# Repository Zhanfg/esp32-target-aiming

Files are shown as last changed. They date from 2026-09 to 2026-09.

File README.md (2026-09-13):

# esp32-target-aiming

ESP32-S3 上的本地视觉目标锁定系统。摄像头找到目标，单片机算角度和轨迹，驱动双轴电机舵盘
把目标压回画面中心。

上位机只在开发期用，负责算法验证和标定。运行时不参与。

## 硬件

| 部件 | 选型 |
|---|---|
| 主控 | ESP32-S3 N16R8（16MB Flash / 8MB PSRAM） |
| 摄像头 | OV2640（主）/ OV5640（备） |
| 电机 ×2 | JGB37-520 12V 有刷减速电机，带霍尔编码器 |
| 驱动 | TB6612FNG 双路 H 桥，一片驱两轴 |
| 反馈 | ESP32 PCNT 硬件正交解码，四倍频 |
| 发射器 | 抽象接口 + 占位实现，型号待定 |
| 工具链 | VSCode + PlatformIO，C++17 |

## 目录

```
esp32-target-aiming/
├─ 00_MASTER_SPEC/      规格书与统一架构方案
├─ 01_PRIOR_ART/        现有来源与专利梳理
├─ 02_REQUIREMENTS/     方案设计、标定推导、硬件接线
├─ 03_CAD/              MST-01A ~ E 结构模型
├─ 04_SIMULATION/       准静态、瞬态、参数扫描
├─ 05_FIRMWARE/         ESP32-S3 固件、算法参考实现、I/O 映射
├─ 06_BOM/              物料清单
├─ 07_EXPERIMENTS/      工具链与 A ~ E 实验
├─ 08_DATA/             实验原始数据
├─ 09_PLOTS/            结果图表
├─ 10_FAILURE_ANALYSIS/ 失效分析
└─ 11_PUBLICATION_NOTES/ 论文与专利记录
```

依赖方向单向向下：`main → control → hal`，`vision` / `calibration` / `comms` 只依赖
`aim_types`，`math` 是公共底座。细节见 [02_REQUIREMENTS/方案设计.md](02_REQUIREMENTS/方案设计.md)。

## 几个设计取舍

先在 PC 上用 Python 把算法跑通再移植到单片机。参数在板子上盲调，出了问题分不清是算法错
还是传感器噪声大。

角度比较一律走 `angle_utils` 的环绕分支。现在按 ±180° 限位，将来换滑环做 360° 连续旋转时
控制算法不用重写。

提前量按执行机构滞后算。激光直瞄没有弹丸飞行时间，前视时间只由三部分组成：驱动延迟、
机械稳定时间、剩余角度除以最大角速度。

发射器需要显式 armed 且处于锁定态才允许触发，急停无条件生效。

## 当前状态

| 阶段 | 内容 | 状态 |
|---|---|---|
| P0 | 仓库骨架、PlatformIO 工程 | 进行中 |
| P1 | 标定层（内参 / 畸变 / 像素↔角度） | 待开始 |
| P2 | 算法核心与 PC 验证 | 进行中 |
| P3 | 视觉流水线 | 待开始 |
| P4 | 电机闭环控制 | 待开始 |
| P5 | 整机标定与精度评估 | 待开始 |
| P6 | 交付文档 | 待开始 |

阶段划分与验收指标见 [02_REQUIREMENTS/方案设计.md](02_REQUIREMENTS/方案设计.md) 第 11 节。

## 安全

这套东西含电机驱动机构和发射器接口。

上电前对照实物原理图核对 `05_FIRMWARE/include/config.h` 里的全部引脚。电机和逻辑分开供电、
单点共地，电机侧并一个 470µF 以上的电解电容。

电机铭牌上的减速比和编码器 PPR 要如实填进配置。这两个数字填错，整条角度链会按比例偏，
而且症状不直观。

发射器相关代码在完成安全评审前不要接真实装置。

## 文档

- [方案设计](02_REQUIREMENTS/方案设计.md)：架构、坐标系约定、算法公式、双环 PID、实施计划与验收标准
- [标定与几何推导](02_REQUIREMENTS/标定与几何推导.md)：针孔模型、畸变与反畸变迭代、像素↔角度互逆性证明、仿射最小二乘、精度预算
- [硬件接线与选型](02_REQUIREMENTS/硬件接线与选型.md)：BOM、引脚分配表、供电与接地、TB6612 真值表、上电检查清单

## 许可

MIT，见 [LICENSE](LICENSE)。

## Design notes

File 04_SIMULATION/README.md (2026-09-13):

# MST-01 数值仿真模型

这是规格书 §23 要求的纯软件力学模型，用 Python 与 numpy 求解，不依赖有限元软件，
也不需要 scipy。模型覆盖 §13 的 A/B/C 三个原型：A 普通膜片，B 单级 snap，
C 双级串联 snap。

模型只服务于静态与动态规律，不证明任何方案更优。§5.3 要求保留单级对照，
并允许得出「双级应被淘汰」的结论，下面的初步结论按模型实际给出的结果写。

## 目录

```text
04_SIMULATION/
├─ README.md
├─ requirements.txt
├─ conftest.py                 # pytest 的路径引导
├─ models/
│  ├─ membrane.py              膜片非线性力—位移
│  ├─ vmt.py                   von Mises truss 双稳单元
│  ├─ chain.py                 一维串联链与元件
│  ├─ solver.py                准静态求解与速度 Verlet 瞬态积分
│  └─ params.py                名义参数、出处与 A/B/C 装配
├─ studies/
│  ├─ common.py                运行、事件检测与输出工具
│  ├─ quasi_static.py          §23.1
│  ├─ transient.py             §23.2
│  └─ parameter_study.py       §23.3
├─ tests/                      模型性质单元测试
└─ results/                    运行后产出的 CSV 与图
```

## 用法

```bash
pip install -r requirements.txt
python studies/quasi_static.py
python studies/transient.py
python studies/parameter_study.py
python -m pytest -q
```

matplotlib 是可选的，缺库时 study 照常出数字与 CSV，只是不产图。

## 模型

### 膜片

把膜片当成预张紧圆膜，夹持边界固定，中心被推杆顶出。采用 Föppl 大挠度薄膜
理论的单模态近似，挠曲形状取抛物线 w(r)=w0(1-(r/a)^2)，解轴对称面内场后积分
应变能再对中心挠度求导，得到

    F(w) = 2·π·N0·w + π·E·t·(7-ν)/(6·(1-ν)·a²) · w³

线性项来自预张力 N0=E·t·ε0/(1-ν)，三次项来自几何大挠度引起的膜内拉伸。
推导步骤写在 `models/membrane.py` 的文件头。抛物线是单模态近似，系数为量级正确，
不是椭圆积分精确解。

假设与局限：轴对称、忽略弯曲刚度、线弹性小应变、预张力与几何拉伸解耦、推杆
半径远小于膜半径。硅胶的粘弹滞后没有建模，会高估回弹能量。挠度接近半径时
误差增大。参数见 `models/params.py`。

### von Mises truss

两根斜杆加可滑动底端。势能写成

    U(h,u) = k_bar·(ℓ-L)² + k_base·u²,  ℓ=sqrt((a+u)²+h²)

给定顶点高度 h，先由 ∂U/∂u=0 解出底端张开量，再用包络定理得到顶点力。
`k_base` 就是规格书 §5.4 与 SRC-04 讨论的边界刚度：它越大越接近锁定支撑，
snap 力随边界刚度单调上升；边界太软时双稳性变弱。这一点在准静态边界敏感性
里可以直接看到。

假设与局限：杆线弹性、忽略杆弯曲与屈曲、忽略摩擦与间隙、底端弹簧线性、
对称二维运动、质量集中在顶点。`k_bar` 是把弹性片弯曲柔度折算到杆轴向的等效
参数，不是材料拉伸刚度，必须实测标定。

### 串联链与求解

A/B/C 都装配成一维串联链。瞬态用力控：外力在 20 ms 内按 smoothstep 升到目标值
后保持。用力控而不是刚性位移驱动，是为了让作动器有明确的力上限，snap 之后
不会持续注入能量。积分用速度 Verlet（kick-drift-kick）固定步长；无阻尼时它是
辛格式，能量误差随步长二阶收敛。力表用三次 Hermite 插值，避免分段线性折点在
高速运动时影响能量。

准静态用位移控牛顿法沿稳定分支前进，输入力的第一个局部极大就是 snap 阈值。
这样不依赖「牛顿失败」这种脆弱判据。到达极限点后停止跟踪。

步长选择：按最高关注频率取周期的 1/100 以下，默认 dt=1e-6 到 5e-7 s；
能量守恒测试用无阻尼自由振动核对，相对漂移在 1e-6 量级。

已知忽略项：摩擦、重力、气压反作用与流体耦合、接触碰撞的细节、膜片面内质量
分布、疲劳与塑性、面外失稳与不对称分岔、作动器自身动力学与柔度、材料粘弹。
这些是最可能让定量结论失真的地方。

## 与规格书 §23 的对应

| 规格书 | 文件 | 产出 |
|---|---|---|
| §23.1 准静态 | `studies/quasi_static.py` | 力—位移、稳定分支、snap 点、级序、边界敏感性 |
| §23.2 瞬态 | `studies/transient.py` | snap 后速度、级间间隔、膜片运动、结构振铃 |
| §23.3 参数扫描 | `studies/parameter_study.py` | 边界刚度、预载、级间失配、膜片刚度、阻尼 |

## 名义参数与出处

| 参数 | 值 | 来源或依据 |
|---|---|---|
| 硅胶膜 E | 1 MPa | 硬度计 30A 量级估计，待实测标定 |
| 硅胶膜 t / a | 0.2 mm / 8 mm | §1.2 横向 15–25 mm 量级 |
| 硅胶预应变 | 5% | 手工张紧安装的典型量级，待实测标定 |
| PET 膜 E / t | 3 GPa / 50 µm | PET 常见范围 2–4 GPa 量级估计，待实测标定 |
| VMT 半跨 / 杆长 | 8 mm / 10 mm | §1.2 核心模块 30–50 mm 长度量级 |
| VMT k_bar | 2000 N/m | 等效参数，名义 k_base 下 snap 力约 1.7 N，与膜片回复力可比，待实测标定 |
| VMT k_base | 1e4 N/m | 接近锁定支撑，保证单级能 snap；扫描变量 |
| engagement gap | 0.6 mm | 量级估计，扫描变量 |
| 顶点质量 | 0.5 g | 零件级量级估计，依赖 CAD，待实测标定 |
| 阻尼 | 0.01 N·s/m | 约单元临界阻尼 1%，等效线粘性，待实测标定 |

## 基于模型的初步结论

这些是模型输出，不是实测结论，必须用 §16 的 A1/B1/C1 实验确认。

### STOP-01 单级 snap 相对普通膜片

同一力曲线下，A 版膜片峰值速度约 0.47 m/s，B 版约 8.9 m/s，模型里单级 snap 的
膜片速度约高 19 倍。触发力约 1.7 N，与失稳单元的 snap 力一致。按这个结果，
STOP-01 没有被触发，单级 snap 值得继续做实验。注意 A 版的 0.47 m/s 是慢推下
膜片自身的响应速度，B 版的速度来自 snap 释放，两者口径一致但含义不同。

### STOP-02 双级是否更差

名义参数（两级相同、gap 0.6 mm）下，C 版膜片峰值速度约 10.6 m/s，只比 B 版高约
18%，输入功却从 20 mJ 升到 38 mJ。事件顺序不稳定：两级相同时第二级先触发，
第一级后触发，间隔 7.21 ms；当第二级刚度比第一级高 1.5 倍以上时顺序翻转成
第一级先触发。整段失配扫描的间隔落在 2.32–4.20 ms，最大 4.20 ms 出现在刚度比
1.0 处。准静态下两级几乎同时到达
fold，静态分不出先后。

按 §30 的口径，双级更复杂、顺序不固定、输出提升有限，本模型倾向于支持 STOP-02，
即回退单级。这个判断只在名义参数与当前模型假设下成立。

### 膜片柔度

膜片刚度扫描显示，峰值输出速度对柔度不是单调：太硬的膜（刚度放大 100 倍）
把速度压到约 3.3 m/s，偏软一侧在刚度放大 0.1 倍处有一个内部低点（7.00 m/s），
之后回升，在刚度放大 0.3 倍到 3 倍之间有一片较宽的最佳区（8.74–9.05 m/s）。
模型没有气动侧，无法直接判断「太软的膜吸收 snap 输出」，只能给出机械侧速度
随柔度的变化。要判断空气脉冲效率，需要在模型里加入气腔与压力，或直接用实验
的 pressure-time 数据。

## 模型依据

- 膜片：Föppl / Hencky 大挠度薄膜理论，单模态（Galerkin）近似，推导见
  `models/membrane.py`。
- 双稳单元：经典 von Mises truss 的双稳势能，配合可滑动底端的边界弹簧；
  串联 snap 与边界刚度可调的概念来源是 SRC-04（Santos 2026），本模型只借用
  概念，不复现其结构或数据。
- 瞬态：速度 Verlet 辛积分，误差二阶收敛；步长收敛由 `solver.convergence_check`
  和测试核对。
- 没有使用 scipy，依赖只有 numpy。

## 没有来源的参数如何处理

`models/params.py` 里每个量都标注了出处或估计依据。材料模量、等效杆刚度、
质量、阻尼、gap 这些没有实测支撑的，写「量级估计，依据：…」或「待实测标定」。
绝对数值不要直接当设计输入，先做 §17 的标定实验。

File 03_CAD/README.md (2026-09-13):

# 03_CAD

结构模型按规格书 §13 的五级原型分开，一级一个子目录：

- `MST-01A/`：普通膜片基线，无 snap-through，低速执行器直接推膜片。
- `MST-01B/`：单级 snap，一个失稳单元。
- `MST-01C/`：双级串联 snap，两个失稳单元，要能判定两级先后。
- `MST-01D/`：可切换边界研究版，locked / released support 或等效的边界改变，带多种预载状态。
- `MST-01E/`：自动供给完整版，6–8 位供给盘、索引机构、Mode B 相关结构。

§14 定了 A → B → C → D → E 的次序，不许跳级，所以目录编号也按这个顺序推进，后续级别在上一级
达标前不动。

设计原则见 §22：模块化（§22.1 要求至少拆成可独立更换的几块）、可拆可测（§22.2，传感靶这类装在运动件
上的附件要能单独拆下做对照）、关键件一体化（§22.3）。§5 的 Stage 1 / Stage 2 两级机械定义和 §6 的
膜片安装方式都会落到具体零件上，失稳单元的候选结构见 §7。

文件名带版本，改了结构就另存一版，别覆盖上一版，方便回查某次实验用的是哪套模型。

## 各级原型的关系

A 到 E 五级沿同一条轴向串联，D 与 E 的核心支持单级与双级两种：

| 级别 | 中间级 | 失稳单元 | 释放卡榫 | 轴向长度 |
|---|---|---|---|---|
| A | 低速执行器直推 | 无 | 无 | 32 mm |
| B | 单个 von Mises truss | 1 个 | 有 | 38 mm |
| C | 两个 von Mises truss 串联 | 2 个 | 有 | 44 mm |
| D | 边界切换加预载 | 1 或 2 个 | 有 | 36 / 47.5 mm |
| E | D 级加 6–8 位供给盘 | 1 或 2 个 | 有 | 46.25 / 58.25 mm。装 6/8 位盘后横向 58.00 / 69.04 mm，超出 §1.2 的 15–25 mm 目标，轴向双级也超出 8.25 mm（`MST-01E` 几何自检，非实测），见 `../00_MASTER_SPEC/DESIGN_DECISION_LOG.md` D-15、`../02_REQUIREMENTS/RISK_REGISTER.md` RSK-16 |

A 没有储能元件，按 §13 是直接推动的基线，不需要释放卡榫。B 与 C 用同一套自锁卡榫加电磁铁拔销的
释放机构。三级共用 FRAME、DIAPHRAGM_MODULE，C 额外多一个 STAGE_2。D 级加 BOUNDARY_MODULE 与
PRELOAD_MODULE，E 级再加 MAGAZINE_MODULE。

## 参数库怎么用

`lib/` 是纯 Python，算尺寸、体积、包围盒、质量都不需要 FreeCAD：

- `lib/params.py`：所有结构尺寸、材料密度、布局锚点、参数来源登记表 `PARAM_SOURCES`。
- `lib/frame.py`：FRAME 模块几何。
- `lib/stage.py`：STAGE_1 / STAGE_2 的 von Mises truss 单元，弹性片是独立件。
- `lib/membrane.py`：DIAPHRAGM_MODULE，膜片加前后两片可拆压环。
- `lib/release.py`：RELEASE_MODULE，自锁卡榫与电磁铁拔销，含自锁余量计算。
- `lib/boundary.py`：BOUNDARY_MODULE，D 级的 locked / released 可切换边界。
- `lib/preload.py`：PRELOAD_MODULE，D 级的可换垫片预载状态。
- `lib/magazine.py`：MAGAZINE_MODULE，E 级的 6/8 位供给盘与索引。
- `lib/checks.py`：件数、包围盒、体积、质量、envelope 对照。
- `lib/freecad_export.py`：把 Solid 列表转 FreeCAD 实体并导出 STEP / FCStd，best-effort。

改尺寸先改 `params.py`，各级 `build.py` 会跟着变。`params.layout(level)` 给出该级沿 Z 的模块区间。

## 重建命令

在 `03_CAD/` 目录下：

```powershell
python MST-01A/build.py
python MST-01B/build.py
python MST-01C/build.py
python MST-01D/build.py                  # 默认单级 locked P0
python MST-01D/build.py --core dual --boundary released --preload P2
python MST-01E/build.py                  # 默认单级 6 位
python MST-01E/build.py --core dual --positions 8
```

每跑一次打印一份几何自检：件数、包围盒、体积、按材料质量估算、模块件数与 envelope 判定。
追加 `--freecad` 会尝试导出 STEP 与 FCStd，当前环境没装 FreeCAD 时会打印跳过提示，不影响自检。

## 与 §22 三条原则的对应

- §22.1 模块化：C 级可拆成 FRAME、STAGE_1、STAGE_2、DIAPHRAGM_MODULE、RELEASE_MODULE 五块，
  外加 OUTPUT 传力杆；B 级去掉 STAGE_2；A 级把中间级换成 ACTUATOR。
- §22.2 可测试性：压环用 M2 螺钉夹紧，松开即可换膜片；失稳单元弹性片由夹块与铰销定位，
  松开夹块螺钉可整片抽出更换；框架顶部敞开，从上方能拍到 snap 过程；自锁卡榫与电磁铁露在外侧。
- §22.3 不要过早一体化：打印件只做框架、夹块、滑块、压环、卡榫座与电磁铁座，弹性件与销都是
  独立标准件或片材，第一版优先看得见、拆得开、测得到。

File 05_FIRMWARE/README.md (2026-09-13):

# MST-01 微型定向脉冲平台固件（第二期）

摄像头与脉冲核心同轴装在旋转云台上。pan 为水平旋转，tilt 为俯仰。两轴各由一台位置
舵机驱动，ESP32-S3 直出 50Hz PWM，或有总线反馈的舵机时读回位置与负载。整机由三块组成：
找目标的视觉、指向目标的云台、产生脉冲的两级串联失稳机械核心。

第二期执行层：舵机指向、两级脉冲核心、旋转供给盘。第一期的电机闭环、TB6612、编码器层
已整体删除。状态机做成双区域：区域 A 管发射周期，区域 B 管指向质量，跨区域用守卫矩阵
约束。故障锁存后唯一清除路径是 `SAFE → HOME`。

架构与安全设计见 `00_MASTER_SPEC/统一架构方案.md` 第 6 节，引脚见 `05_FIRMWARE/io-map.md`，
故障码见 `05_FIRMWARE/fault-codes.md`。

## 1. 构建 / 烧录 / 监视

```bash
cd 05_FIRMWARE

# 编译（开发环境，带逐帧遥测）
pio run

# 编译并烧录
pio run -t upload

# 打开串口监视器（115200）
pio device monitor

# 发布环境（-O2、关闭逐帧遥测）
pio run -e esp32-s3-devkitc-1-release
```

> 环境：VSCode + PlatformIO（Arduino 框架）+ C++17。外部库只依赖 `espressif/esp32-camera`，
> LEDC、I2C、Preferences 都来自 Arduino-ESP32 内置的 ESP-IDF 组件。

## 2. 上电前核对

`include/config.h` 里带 `// 待实测标定` 的引脚和参数都是占位默认值。首次烧录前重点确认：

- 摄像头 DVP 数据线 `CAM_PIN_Y2..Y9` 的顺序。接错会黑屏或花屏，一般不会损坏硬件。
- 舵机 PWM 脚（PAN_CMD=14、TILT_CMD=21）与摄像头、USB、Flash/PSRAM 占用脚不冲突。
- I2C0（GPIO45/46）是 strapping 脚，外接上拉会影响复位电平，必须核对。
- MCP23017 输入的外部上拉/下拉已按信号极性就位：许可类（FIRE_INHIBIT、EXTERNAL_ALLOW）
  外部下拉、开路即禁止；`MECH_RECOVERED` 常闭干接点对地、外部上拉。
- 参考开关 `PAN_HOME`、`TILT_HOME` 的触发方向与 `HOME_*_DIR` 一致，否则归零会超时进 FAULT。
- 释放链硬件与门树、单稳态与负载开关已搭好，且逐条断开输入时释放无动作（架构文档 §6.11）。

## 3. 模块职责

| 文件 | 职责 |
|---|---|
| `platformio.ini` | 构建配置：芯片、PSRAM、Flash 分区、依赖、编译开关、发布环境 |
| `include/config.h` | 全部引脚、机械参数、安全阈值、通信参数 |
| `src/aim_types.h` | 双区域状态、故障码、跨模块数据结构 |
| `src/math/angle_utils.*` | 角度归一化、角差、限速趋近 |
| `src/hal/servo.*` | 舵机抽象：PWM 实现 + 总线占位实现，编译期选择 |
| `src/hal/io_expander.*` | MCP23017 的 I2C0 驱动，读失败落安全侧 |
| `src/hal/safety_gate.*` | 软件互锁判定与武装锁存，硬件与门之外的第二层 |
| `src/hal/transmitter.*` | 第一期发射器抽象，第二期由四路命令层取代，保留占位 |
| `src/control/servo_axis.*` | 单轴指向控制：限幅、变化率限制、有反馈时位置校正 |
| `src/control/home.*` | 上电归零五步流程，参考开关 + 3 秒超时 |
| `src/calibration/*` | 内参、畸变、仿射标定的存取与最小二乘解算 |
| `src/vision/*` | 取帧、降采样、HSV、连通域、亚像素质心 |
| `src/comms/telemetry.*` | 串口 CSV 遥测与事件行 |
| `src/main.cpp` | 初始化、双区域状态机、安全策略、看门狗 |

## 4. 遥测格式

固件走两条遥测线，前缀不同，用途不同。

`MST,` 是规格书 §19 的实验记录，每发一条，17 个字段：

```
MST,timestamp,experiment_id,prototype_version,mechanism_version,mode,boundary_state,
    preload_state,membrane_id,payload_id,cycle_count,stage1_event,stage2_event,
    mechanism_recovered,magazine_position,magazine_index_ok,fault_code,operator_note
EVT,<t_ms>,<tag>,<message>
```

`DIAG,` 是每控制拍的帧轨迹，由 `AIM_VERBOSE_TELEMETRY` 控制，开发期打开、发布期关闭，
16 个字段：

```
DIAG,timestamp_ms,loop_us,obs_valid,obs_dropped,px,py,confidence,
     pan_deg,tilt_deg,pan_target_deg,tilt_target_deg,
     err_pan_deg,err_tilt_deg,err_deg,aim_state,has_feedback
```

`err_deg` 是目标质心相对光轴的角偏差合成量，静态指向 RMSE 按它算；`loop_us` 是控制周期；
`aim_state` 的 3 与 4 对应 TRACKING 与 LOCKED，据此算锁定建立时间。字段口径见
`src/comms/telemetry.h`。

发布环境（`AIM_VERBOSE_TELEMETRY=0`）只留 `MST,` 低频心跳行，`DIAG,` 行不输出。故障码见
`fault-codes.md`。

## 5. 安全要点

- 释放链的物理门控由外部与门与负载开关保证，软件互锁只是第一道闸（架构文档 §6.6）。
- `FAULT` 锁存，`FAULT → READY` 不存在；软故障用 `CLEAR` 后走 `SAFE → HOME`，硬故障需断电。
- 归零期间释放链强制断开，参考开关未全中不进入 `READY`。
- 无反馈 PWM 舵机不能检测失速，失速检测依赖总线舵机反馈或电流监控，需台架验证。

## 6. 批次编号命令

膜片与载荷的批次号供实验追溯，来源只能是操作者输入。串口命令写入后存 NVS（命名空间
`aim_batch`，键 `membrane`、`payload`），断电不丢，上电由 `setup()` 读回，组装遥测时填入
`membrane_id`、`payload_id`。两字段都是 uint16，取值 0 .. 65535，0 表示未设置。

```
SET MEMBRANE <id>    # 设膜片批次编号
SET PAYLOAD <id>     # 设载荷批次编号
STATUS               # 输出 ST,membrane_id,<n> 与 ST,payload_id,<n>
```

参数非数字或超出 0 .. 65535 会报错并保持原值；NVS 写入失败也会回退原值。这两条命令在
`calib_shell` 的 `HELP` 里也能查到。

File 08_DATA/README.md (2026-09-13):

# 08_DATA

实验原始数据落在这里。§20 这个目录本身不分子目录，用文件名区分实验与日期。

字段定义、CSV 约定、枚举对照和各级数据文件与列定义表的对应，见 `DATA_SCHEMA.md`。
本文只给目录用途和归档流程。

每次动作保存一行，字段按规格书 §19：

```
timestamp
experiment_id
prototype_version
mechanism_version
mode
boundary_state
preload_state
membrane_id
payload_id
cycle_count
stage1_event
stage2_event
mechanism_recovered
magazine_position
magazine_index_ok
fault_code
operator_note
```

A 到 E 各级的采集记录都进这里，`experiment_id` 里带上原型级别，免得混在一起。遥测原始 CSV 可以先
留在 `07_EXPERIMENTS/` 对应级别下，按 `DATA_SCHEMA.md` 的列定义整理成规范字段后再归档到这里。
出图的数据从这份表读，不要在 `09_PLOTS/` 里手改数据。

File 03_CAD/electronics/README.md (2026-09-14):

# MST-01 释放门控电路板（release-gate）

本目录是释放路径的硬件门控板。它把统一架构方案 §6.6 的与门树、§6.5 的 H1/H2/H3/H4/H6
做成实体电路，让固件即使卡死或输出错误电平，也放不出一次释放。对应主规格 §10.3 的
`RELEASE_CMD` 输出与 §11 的四条互锁。

架构 §6.11 第一条说得很直接：这条不通过，后面所有状态机都是纸面。所以本板的设计重点不在
控制精度，而在每一个输入的失效方向，以及一块被卡住的 MCU 能造成什么。

信号极性和接口以 `02_REQUIREMENTS/interfaces.md` 第 5 节为准，引脚沿用
`05_FIRMWARE/include/config.h` 的 `RELEASE_CMD_PIN`、`STAGE1_STATE_PIN`、`STAGE2_STATE_PIN`
等定义。两者不一致时以接口文档为准，本板按接口文档的电平做。

## 1. 文件与用途

| 文件 | 用途 |
|---|---|
| `README.md` | 本文：设计说明、逻辑推导、极性表、H1 到 H6 落点、单点失效分析 |
| `release-gate.kicad_sch` | 原理图，KiCad 10 S-expression，含完整网表 |
| `release-gate.kicad_pcb` | 板图初版：外形、安装孔、布局、网表、地平面、执行链局部走线 |
| `release-gate.kicad_pro` / `.kicad_prl` | KiCad 打开时自动生成的工程文件 |
| `release-gate-schematic.pdf` / `.svg` | 原理图导出，供快速查看 |
| `release-gate-pcb.pdf` / `.svg` | 板图导出 |
| `bom.csv` | 物料清单，含位号、型号、数量、封装、作用 |
| `test-procedure.md` | 板级验证步骤，搭板后照做 |

本板不承担 H5（超出机械限位）。H5 由结构件上的物理止挡实现，见 `03_CAD` 各机型的结构件。

## 2. 供电与地

板上有两条供电，进板后各自串自恢复保险丝和防反：

- 逻辑轨 `+3V3`：从主控逻辑电源引入，经 `D14`（SS14 防反）与 `F1`（MF-MSMF050）。
  供五片 74HC、上拉/下拉和继电器（本版无继电器）。
- 执行轨 `V_ACT_IN`：从舵机与执行器电源引入，先过 `J7` 上的急停常闭触点变成 `V_ACT_SW`，
  再经 `F2`（MF-MSMF200）到释放电磁铁，另经 `F3`（MF-MSMF110）到预载执行器。
- 单点共地。逻辑地与执行地在板上汇到同一块铺铜，不另做隔离，避免地环路。

急停之后才出现 `V_ACT_SW`，这一点让急停独立于任何逻辑元件。后面所有 MOS 开关都只能
在 `V_ACT_SW` 存在时给执行器供电。

## 3. 与门树

### 3.1 逻辑表达式

```
Q1 = FIRE_INHIBIT_N · EXTERNAL_ALLOW · MECH_RECOVERED_N · POCKET_OR_MODE_A
Q2 = Q1 · ARMED_LATCH · RELEASE_PULSE · MASTER_ENABLE_GATED
MASTER_ENABLE_GATED = MASTER_ENABLE_RAW · FAULT_OK
FAULT_OK            = NOT(FAULT_LATCH)
POCKET_OR_MODE_A    = POCKET_ALIGNED OR MODE_A_RAW
```

Q2 经 `R22` 驱动低边 MOSFET `M1` 的栅极。M1 导通，释放电磁铁才通电；Q2 为低或悬空时 M1
关断。整条链上任何一级为假，释放都不可能发生。

### 3.2 器件选择

工程实践里做四输入与门，直接用一片 74HC21 最省。74HC21 是双 4 输入与门，一片正好给出
Q1 和 Q2 两级，不需要用 74HC08 拼树，也不用二极管与门凑，输入数、门数、传播延迟都对得上。
逻辑轨 3.3V，74HC 系列在 3.3V 下的输入阈值和驱动能力都够用。

其余逻辑按功能配：

- `U2` 74HC123：双可重触发单稳态，一半做释放脉宽钳位，一半做归零复位脉冲。
- `U3` 74HC74：双 D 触发器，一半做故障锁存，一半做武装锁存，异步置位/复位正好用来接
  故障置位和归零复位。
- `U4` 74HC11：三 3 输入与门，做三处 HOME 的与、武装时钟门、取消武装逻辑。
- `U5` 74HC14：六施密特反相器，做极性取反和慢边沿整形。
- `U6` 74HC08：四 2 输入与门，把故障锁存输出接进主使能和预载使能。

### 3.3 输入极性与开路行为

每个输入都按“开路即禁止”配偏置。外部上拉或下拉只是并上去，板端自己的偏置保证接插件
松脱、断线、掉电时落到禁止侧。执行器电源上的急停触点另算，它断的是功率。

| 信号 | 有效方向 | 板端偏置 | 开路结果 | 落点 |
|---|---|---|---|---|
| `FIRE_INHIBIT_N` | 高 = 未否决 | `R1` 10k 下拉，`R2` 串联 10k，`C1` 100n | 拉到低 | 否决，Q1 为假 |
| `EXTERNAL_ALLOW` | 高 = 许可 | `R3` 10k 下拉，`R4` 串联 10k，`C2` 100n | 拉到低 | 拒绝，Q1 为假 |
| `MECH_RECOVERED_RAW` | 低 = 机构已复位 | `R7` 10k 上拉，`C4` 100n | 拉到高 | 经 `U5A` 反相为低，Q1 为假 |
| `POCKET_ALIGNED` | 高 = 载荷对齐 | `R5` 10k 下拉，`R6` 串联 10k，`C3` 100n | 拉到低 | 对齐不满足，Q1 为假 |
| `MODE_A_RAW` | 高 = 模式 A 旁路 | 经 `JP1` 与外部常闭触点，`R27` 100k 下拉 | 拉到低 | 撤销旁路，退回要求真实对齐 |
| `ARM_CMD` | 高 = 请求武装 | `R8` 10k 下拉，`C5` 100n | 拉到低 | 不武装 |
| `DISARM_CMD` | 高 = 取消武装 | `R9` 10k 下拉，`C6` 100n | 拉到低 | 不取消，见 3.4 |
| `FAULT_CMD` | 高 = 软件请求故障 | `R10` 10k 下拉，`C7` 100n | 拉到低 | 不置故障，见 3.4 |
| `MCU_RELEASE_CMD` | 高 = 释放请求 | `R12` 10k 下拉，`R11` 串联 1k，`C8` 100n | 拉到低 | 无请求 |
| `MASTER_ENABLE_RAW` | 高 = 主使能有效 | `R18` 10k 下拉，`C13` 100n，且串急停触点 | 拉到低 | Q2 为假 |
| `PAN_HOME` / `TILT_HOME` / `MAG_HOME` | 高 = 已触发 | `R15` / `R16` / `R17` 10k 下拉，`C10` 到 `C12` 100n | 拉到低 | 视为未归零，故障锁存不能复位 |

`FIRE_INHIBIT_N` 与 `EXTERNAL_ALLOW` 的静态偏置在接口文档里规定为外部 10k 下拉，板端再各
并一只下拉，断线时两处都往低走。

### 3.4 两处不落到禁止侧但可接受的开路

`FAULT_CMD` 与 `DISARM_CMD` 开路时都拉到低。低电平分别表示“不置故障”和“不取消武装”。
两者都不是禁止侧电平，但它们本身只是软件发起的动作请求，缺失不会让释放更容易发生：
置故障是让系统更安全，取消武装也只是把武装锁存清零。真正的拦截已经由
`FIRE_INHIBIT_N`、`EXTERNAL_ALLOW`、`MASTER_ENABLE_RAW` 和故障锁存承担。这里如实标出，
免得把“开路即禁止”一概而论。

## 4. 单稳态钳时

### 4.1 电路

`MCU_RELEASE_CMD` 从 `J3` 进来，串 `R11`、对地 `C8`，接到 `U2A` 的 B 触发端（引脚 2）。
`U2A` 的 A 端（引脚 1）接 `GND`，使上升沿触发；`CLR`（引脚 3）接 `+3V3`。输出 Q（引脚 4）
是 `RELEASE_PULSE`，接到 Q2 的一个输入。RC 定时网络是 `R19` 与 `C15`，分别接在
`1REXT`（引脚 7）与 `1CEXT`（引脚 6）。

GPIO 直连的长驱动不再存在，释放命令必须先过这一级。MCU 把 `RELEASE_CMD` 拉高并保持，
单稳只输出一个固定宽度的脉冲，之后回到低，不会持续通电。

### 4.2 脉宽计算

74HC123 的脉宽按数据手册：

```
t_W ≈ K · R_EXT · C_EXT
```

其中 `K` 在 `C_EXT ≥ 1000 pF`、`VCC = 3.3V` 附近典型值约 1.0。取

- `R19 = 33 kΩ`，`C15 = 1 µF`，得 `t_W ≈ 33 ms`。

固件侧的软件脉宽是 `RELEASE_PULSE_MS = 30 ms`。硬件上限略大于软件脉冲，正常工作时由软件
结束释放，硬件不截断；MCU 卡在输出高时，硬件在约 33 ms 后强制关断。两侧都留了容差，实际
脉宽受电容容差（约 ±10%）、电阻容差和 `K` 的温度漂移影响，台架上用示波器测 `RELEASE_PULSE`
实测宽度，按结果微调 `C15`。执行器若需要更长动作时间，加大 `C15` 后重新验证。

`U2B` 用同样的公式做归零复位脉冲：`R20 = 22 kΩ`，`C16 = 1 µF`，得约 22 ms。

单稳是可重触发的。MCU 卡高只给一个上升沿，所以是一个脉冲；固件在释放脉冲有效期内不得
再次翻转 `RELEASE_CMD`，否则会把脉冲续长，这一条写进固件约束。

## 5. 负载开关

释放电磁铁的回流路径上串低边 N 沟道 MOSFET `M1`（AO3400A，SOT-23）：

- 栅极由 `Q2_OUT` 经 `R22`（100Ω）驱动，栅源之间有 `R21`（100k）下拉。Q2 悬空或走线断开时
  `R21` 把栅极拉到 `GND`，M1 关断。
- 漏极接 `EMAG_LO`（电磁铁回流端），源极接 `GND`。
- 电磁铁两端反并 `D1`（SS34），阴极朝 `EMAG_HI`，关断瞬间给感性电流一条续流回路。
- `V_ACT_SW` 到 `EMAG_HI` 之间串 `F2`（MF-MSMF200 自恢复保险丝），短路或堵转时限流。
- `V_ACT_SW` 对地挂 `D13`（SMBJ16A）做瞬态钳位。

预载执行器走同样结构：`M2` 栅极由 `PRELOAD_ENABLE` 驱动并带 `R23` 下拉，漏极 `PRELOAD_RET`
接 `J4` 的 2 脚。它的源极在板上不直接接地，改从 `J4` 的 3 脚 `MECH_RET` 引出，装机时把
机构常闭触点串进去再回地。机构未复位，触点断开，预载执行器在物理上没有回流路径。

## 6. 故障锁存器

### 6.1 电路

故障锁存用 `U3A`（74HC74 的一半）：

- 置位 `/1S`（引脚 4）接 `FAULT_SET_N`，由 `R29` 上拉，被 `U5E`（`FAULT_CMD` 反相）或
  急停辅助触点（`J7` 的 5、6 脚，常开对地）拉低时置位。
- 复位 `/1R`（引脚 1）接 `FAULT_RESET_N`，由 `R30` 上拉，被 `U2B` 的 `/Q`（引脚 13）
  或上电复位网络拉低时清零。
- 输出 `Q`（引脚 5）是 `FAULT_LATCH`，高表示故障已锁存并且保持。

`FAULT_LATCH` 经 `U5B` 取反成 `FAULT_OK`。`FAULT_OK` 进 `U6A`，与 `MASTER_ENABLE_RAW` 相与
得到 `MASTER_ENABLE_GATED`，作为 Q2 的一个输入；同时进 `U6B`、`U6D`，与 `PRELOAD_CMD`、
`MECH_RECOVERED_N` 相与得到 `PRELOAD_ENABLE`。故障一旦锁存，主使能被切断，预载也使能被切断。

### 6.2 为什么必须重新归零由电路保证

复位脉冲不是简单地把三处 HOME 相与。三处 HOME 先进 `U4A` 得到 `HOME_AND`，再送 `U2B` 的
B 端。`U2B` 只在 `HOME_AND` 的上升沿触发一次，输出一个约 22 ms 的低脉冲去清零 `U3A`。

这样处理有两个后果。机构停在非零位时 `HOME_AND` 为低，故障清不掉；要把三轴都驱动到参考
开关并同时触发，才会出现一次上升沿。如果故障发生时机构恰好已经停在三处零位，`HOME_AND`
没有边沿，锁存同样清不掉，必须先离开零位再重新归零。复位只发生在物理归零完成的瞬间，
软件无法凭一个 GPIO 把锁存清掉。

上电复位由 `R28`、`C14` 产生 `POR_N`，通过 `D11`、`D12` 分别接 `FAULT_RESET_N` 与
`ARM_RESET_N`，保证上电时两个锁存都从清零态开始，直到第一次真实归零。

## 7. 急停

急停用常闭蘑菇头，三个触点全部走 `J7`，不经过 MCU：

- 触点一（`J7` 1、2 脚）：串在执行轨里，`V_ACT_IN` 与 `V_ACT_SW` 之间。按下就断开执行轨，
  释放电磁铁和预载执行器同时失去供电。这条对应 H6。
- 触点二（`J7` 3、4 脚）：串在 `MASTER_KEY` 与 `MASTER_ENABLE_RAW` 之间。按下就让 Q2 的
  主使能输入变低。
- 触点三（`J7` 5、6 脚）：常开对地，按下时把 `FAULT_SET_N` 拉低，故障锁存置位。

按一次急停，执行轨断电、主使能断开、故障锁存置位三件事同时发生，而且都不依赖固件。

## 8. 模式 A 旁路

供给盘相关的对齐信号在模式 A 用旁路成真。旁路用外部常闭触点加焊接跳线 `JP1` 实现，
不靠继电器吸合直接给信号：

- `J6` 提供 `+3V3`（1 脚）、`MODE_A_SW`（2 脚）、`GND`（3 脚）。装机时把供给盘不在位时
  闭合的常闭触点接在 1、2 脚之间。
- `MODE_A_SW` 经 `JP1` 到 `MODE_A_RAW`，再由 `D7` 与 `POCKET_ALIGNED`（经 `D8`）做二极管或，
  节点 `POCKET_OR_MODE_A` 用 `R26` 100k 下拉后进 Q1。
- 供给盘没装时触点闭合，`MODE_A_RAW` 被拉高，旁路成立，模式 A 可以动作。装上盘后触点断开，
  `R27` 把 `MODE_A_RAW` 拉到低，旁路撤销，必须 `POCKET_ALIGNED` 为高才放行。默认状态落在
  模式 A 无载荷这一侧，符合架构 §6.5 的 H3。

需要跑模式 B 时把 `JP1` 拔掉，旁路彻底失效，只认对齐传感器。这一步写进模式 B 的作业流程。
另外要说明，如果供给盘实际已装但常闭触点卡在闭合，旁路会误成立，属于单点失效，见第 11 节。

## 9. ARMED_LATCH

`ARMED_LATCH` 由硬件锁存给出，用 `U3B`（74HC74 的另一半），不是 MCU 的普通 GPIO。

理由是架构 §6.9 第 8 条已经指出纯软件武装是缺陷。若武装只由一个 GPIO 表示，卡住的 MCU
可以直接把它拉高，与门树就少了一道。做成硬件锁存后，武装有三个条件同时满足才会成立：

```
ARM_CLK = Q1_OUT · ARM_CMD        （U4B 输出）
```

`ARM_CLK` 接到 `U3B` 的时钟端（引脚 11），`D` 端（引脚 12）接 `+3V3`，所以时钟上升沿把
`ARMED_LATCH` 置高并保持。要出现这个上升沿，`Q1_OUT` 必须已经为真，也就是外部许可、
安全否决、机构复位、对齐这几路全部成立，同时 MCU 给一次 `ARM_CMD`。MCU 单独把 `ARM_CMD`
钉在高不会重复置位，因为 `U3B` 是边沿触发。

清零走 `ARM_RESET_N`（`U4C` 输出）：

```
ARM_RESET_N = FAULT_OK · REL_IDLE · DISARM_CMD_OK
REL_IDLE    = NOT(RELEASE_PULSE)
```

故障锁存置位、一次释放脉冲结束、或 MCU 给 `DISARM_CMD`，都会把武装锁存清掉。这样一次
武装对应一次释放，发完自动回到未武装。上电由 `D12` 把 `ARM_RESET_N` 拉低清零。

## 10. H1 到 H6 的落点

| 硬约束 | 在本板上的落点 |
|---|---|
| H1 释放能量路径受多重条件约束 | `U1`（74HC21）构成 Q1 与 Q2 两级与门；`U2A` 把释放命令钳成单脉冲；`M1` 低边开关串回流路径；`F2` 限流；急停触点串执行轨。Q2 为假时 M1 关断 |
| H2 机构未复位时预载无法驱动 | `M2` 源极不接板地，经 `J4` 3 脚引到机构常闭触点再回地，触点断开时物理断路；逻辑上再经 `U6B`、`U6D` 与 `MECH_RECOVERED_N` 相与 |
| H3 模式 B 未对齐时释放无法完成 | `POCKET_ALIGNED` 经 `D8` 进 Q1；模式 A 由 `J6` 常闭触点加 `JP1`、`D7` 旁路，默认落在无载荷一侧 |
| H4 故障与急停锁存，未重新归零不能复位 | `U3A` 故障锁存；复位由 `U2B` 对 `HOME_AND` 上升沿的单稳脉冲驱动；锁存输出经 `U6A`、`U6B` 切主使能与预载 |
| H5 超出机械限位 | 本板不承担，由结构件物理止挡实现 |
| H6 主电源急停 | `J7` 的常闭触点直接串 `V_ACT` 与主使能键路，不经 MCU；辅助触点置故障锁存 |

## 11. 单点失效分析

下面列出会导致误释放的元件失效。误释放指在没有满足全部许可条件、或 MCU 不该发出释放时，
释放电磁铁仍被通电。

| 失效元件 | 失效方式 | 后果 | 板上是否有冗余或缓解 |
|---|---|---|---|
| `U2A`（74HC123） | 输出对 `+3V3` 短路或内部失效使 Q 恒高 | 时间钳位失效，只要 Q1、`ARMED_LATCH`、主使能成立就持续通电 | 无。缓解只能靠急停，建议改版加第二把串联器件或双单稳 |
| `M1`（AO3400A） | 漏源短路 | 不依赖栅极，`V_ACT_SW` 存在时电磁铁就通电 | 急停常闭触点串在 `V_ACT_SW` 之前，可断电；`F2` 只限流不切断 |
| `MOS_GATE_RELEASE` 走线 | 短到 `+3V3` | 绕过 Q2 使 M1 恒导通 | 急停可断电；建议改版在栅极串第二只受主使能控制的器件 |
| `U6A`（74HC08） | 输出卡高 | `MASTER_ENABLE_GATED` 恒高，故障锁存切不断主使能 | 无自动缓解，只能重新上电走 POR |
| `U5B`（74HC14） | 输出卡高使 `FAULT_OK` 恒高 | 故障切不断主使能与预载 | 无自动缓解 |
| `FIRE_INHIBIT_N` 线 | 短到 `+3V3` | 安全否决失效（对应 FM-08） | 板上无。需要架构 §6.7 提的双冗余触点交叉校验，本版留了位置未做 |
| `POCKET_ALIGNED` 线 | 短到 `+3V3` | 对齐失效，模式 B 可放出未对齐载荷 | 拔掉 `JP1` 不能阻止这一个，仍需双通道 |
| `MECH_RECOVERED_RAW` 线 | 短到 `GND` | 被当成已复位，Q1 与预载逻辑都放行 | 无。断线方向是安全的，短到地是危险方向 |
| `EXTERNAL_ALLOW` 线 | 短到 `+3V3` | 伪许可 | 无，需双通道 |
| `JP1` 与供给盘触点 | 盘已装但触点卡在闭合 | 模式 B 下旁路对齐 | 模式 B 流程要求拔掉 `JP1`，可消除这一条 |
| `U4C`（74HC11） | 输出卡高使 `ARM_RESET_N` 恒高 | 故障后武装锁存清不掉，只能上电复位 | 不影响误释放，但削弱互锁，建议改版用两把器件 |

不会导致误释放的失效方向也列出，说明哪些地方失效是安全的：`U3B` 失电或卡低使武装不成立；
`U5A` 失效使 `MECH_RECOVERED_N` 为低；`U5C` 卡高使 `REL_IDLE` 为高只是不能清零武装；任一
输入下拉丢失让对应条件不成立。这些方向都落到不释放。

冗余现状：急停有两个独立触点分别断执行轨和断主使能，这一点是冗余的。故障复位要求物理
归零序列，不能由单个信号清掉。架构 §6.7 与 §6.6 提到的双通道冗余触点交叉校验、安全输入
短路到 3V3 的检出，本版没有实现，是本板需要补的最大缺口。安全完整性做到哪一级要由后续
试验确认，设计上先按双通道留位。

## 12. 连接器与对外接口

| 连接器 | 引脚 | 说明 |
|---|---|---|
| `J1` PWR_IN | 1 `V_ACT_IN`，2 `+3V3`，3、4 `GND` | 电源输入 |
| `J2` ACT_OUT | 1 `EMAG_HI`，2 `EMAG_LO`，3 `GND` | 释放电磁铁 |
| `J3` SAFETY_IN | 20 脚，含 `FIRE_INHIBIT_N`、`EXTERNAL_ALLOW`、`MECH_RECOVERED_RAW`、`POCKET_ALIGNED`、`ARM_CMD`、`DISARM_CMD`、`FAULT_CMD`、`MCU_RELEASE_CMD`、`PRELOAD_CMD` 与多地 | 安全与控制输入 |
| `J4` PRELOAD_OUT | 1 `PRELOAD_HI`，2 `PRELOAD_RET`，3 `MECH_RET` | 预载执行器，3 脚外接机构常闭触点回地 |
| `J5` HOME | 1 `PAN_HOME`，2 `TILT_HOME`，3 `MAG_HOME`，4 `GND` | 三处参考开关 |
| `J6` MODE_MAG | 1 `+3V3`，2 `MODE_A_SW`，3 `GND` | 供给盘在位常闭触点 |
| `J7` ESTOP | 1、2 执行轨；3、4 主使能；5、6 故障置位 | 急停三触点 |
| `J8` KEY | 1 `+3V3`，2 `MASTER_KEY`，3 `GND` | 人工总开关或钥匙 |
| `J9` STATUS | `FAULT_LATCH`、`ARMED_LATCH`、`HOME_AND_N`、`Q2_OUT`、`MECH_RECOVERED_RAW`、`MECH_RECOVERED_N`、`READY_DIAG`、`GND` | 状态回主控，注意 `HOME_AND_N` 是反相后的低有效 |

`J9` 的 `Q2_OUT` 可以让固件读到释放门此刻是否被打通，作为软件自检之外的第二路确认。
`MECH_RECOVERED_RAW` 直接引回主控的 MCP23017 输入位 6，板上同时用它和它反相后的
`MECH_RECOVERED_N`，方向与接口文档 §3.2 一致（原始位低表示已复位）。

## 13. KiCad 生成与验证状态

本机安装了 KiCad 10.0.5，命令行 `kicad-cli` 与 `pcbnew` 的 Python 模块可用。我没有可用的
`kicad_*` MCP 工具，所以原理图与 PCB 是用脚本调用 KiCad 的 Python 接口和文本格式生成的，
不是纯手写后没经过任何工具。

实际跑过的验证：

| 项目 | 命令 | 结果 |
|---|---|---|
| 原理图网表 | `kicad-cli sch export netlist` | 成功，97 个符号实例（含 2 个 ERC 电源旗标，实际采购件 95 个）、60 个网络，逻辑节点与本文一致 |
| 原理图 ERC | `kicad-cli sch erc --severity-all` | 0 条 error；97 条 `lib_symbol_issues` 警告，原因是内联符号库 `rg` 未注册进 `sym-lib-table`，不影响网表与显示 |
| 原理图导出 | `kicad-cli sch export pdf` / `svg` | 成功，PDF 与 SVG 已在本目录 |
| PCB DRC（自动布线前） | `kicad-cli pcb drc --severity-all` | 1 条丝印重叠警告；151 个未连接项来自信号布线尚未做完 |
| PCB DRC（自动布线并重灌铜箔后） | 同上 | 20 条违规（19 条线宽、1 条丝印）加 23 个未连接项。详见第 14 节 |
| PCB 导出 | `kicad-cli pcb export pdf` / `svg` | 成功 |

说明两点。原理图的连接用贴在引脚端点的网络标签表达，不是逐段连线的画法，电气连接正确，
但观感上与手工画的图不同。PCB 是初版布局：外形、安装孔、去耦、地平面、执行器供电与栅极
驱动这几段已经布通，其余信号的铜线还没走完，所以 DRC 有 151 个未连接项。这些文件没有用
KiCad 图形界面逐屏人工检查过，上面的结论全部来自 `kicad-cli`。

## 14. 已知缺口与下一步

1. 双通道冗余触点与安全输入短路到 3V3 的检出尚未实现。这是 FM-08 与 §6.7 的缺口，也是
   本板最该先补的部分。
2. 信号布线已自动布通大半，但未干净。用 Freerouting 2.4.1（JAR 在 `~/.kicad-mcp/freerouting.jar`）
   自动布线，未连接项从 151 降到 23。管线是：`pcbnew.ExportSpecctraDSN` 导出 DSN、
   `java -jar freerouting.jar -de <dsn> -do <ses> --gui.enabled=false -mp 30` 布线、
   `pcbnew.ImportSpecctraSES` 回导、`pcbnew.ZONE_FILLER` 重灌铜箔。**重灌那一步不能省**，
   否则铜箔没避让新走线，DRC 会把 511 处报成短路。

   两个残留问题。一是线宽：DSN 里的规则写的是 `(width 200)`（0.2 mm），工程 netclass 也是 0.2 mm，
   但 Freerouting 实际用了 0.15 mm，留下 19 条线宽违规。二是 23 个未连接项，Freerouting 只报 2 条
   布不通，其余应该是重灌铜箔后不再靠铺铜糊住的连接。正式投板前这两项都要清掉。
3. 执行器电流尚未冻结。`M1`、`F2`、`D1` 的规格按中小电流电磁铁选的，执行器定型后按峰值
   电流与浪涌时间复核，必要时换更大封装的 MOSFET 和保险丝。
4. 归零复位脉宽与释放脉宽都要在台架实测后微调，见 `test-procedure.md`。
5. 本板按模式 A 默认安全侧设计。模式 B 的作业流程必须包含拔除 `JP1`,否则旁路会在盘已装
   时留下误释放通道。

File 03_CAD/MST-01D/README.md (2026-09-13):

# MST-01D 可切换边界研究版

## 目的

§13 的 D 级。在 B/C 的单级或双级核心上加可逆的边界改变与多种预载状态，用来建立
boundary state → mechanical response 的实验映射，对应 §16 Test D1 的 BOUNDARY_0 /
BOUNDARY_1 两个状态。§5.4 把边界调整定位成研究变量，不进默认专利主张，所以这里
优先把状态做得可切换、可复现、能拍到。

## 模块与文件

- `build.py`：装配 FRAME、RELEASE_MODULE、BOUNDARY_MODULE、PRELOAD_MODULE、
  失稳单元（单级或双级）、OUTPUT、DIAPHRAGM_MODULE 并自检。
- FRAME、RELEASE_MODULE、DIAPHRAGM_MODULE：与 B/C 同一套。
- BOUNDARY_MODULE：浮动托架加两根 Y 向锁销，切换 locked / released。
- PRELOAD_MODULE：可换垫片堆，设定预载状态。
- 失稳单元与 OUTPUT：单级时一个单元，双级时两个串联加级间垫片。

## 级数做成参数

统一架构 §3.2 记录模型预警：纯软件模型下双级相对单级膜片峰值速度只多约 18%，
输入功接近翻倍，级序还会在刚度失配下翻转，可能回退单级。边界研究不该绑死在级数
上，所以 `build.py` 用 `--core single|dual` 切换，几何布局由
`params.layout("D", core)` 给出。两种核心共用同一套边界与预载模块。

| 核心 | 件数 | 包围盒 X×Y×Z (mm) | 体积 (mm³) | 质量估算 (g) |
|---|---:|---|---:|---:|
| single locked P0 | 42 | 22.00 × 22.00 × 36.00 | 8603.1 | 15.80 |
| dual locked P0 | 52 | 22.00 × 22.00 × 47.50 | 9480.9 | 17.41 |
| dual released P0 | 52 | 22.00 × 22.00 × 47.50 | 9480.9 | 17.41 |
| dual released P3 | 55 | 22.00 × 22.00 × 47.50 | 9821.6 | 18.04 |

单级轴向 36.0 mm、双级 47.5 mm，横向都是 22.0 mm，均落在 §1.2 的 envelope 内。
预载从 P0 到 P3 只增 3 片垫片，件数与质量略增，包围盒不变。

## 边界状态的切换方式与可复现性

`BOUNDARY_MODULE` 把第一级底夹块从框架上挪到一块 Z 向浮动的托架里。托架两侧由两
根 Y 向导柱做面外导向，顶面留两个销孔。

- locked：两根 Y 向锁销插到底，穿过销孔把托架压死在框架上，边界走刚性支路，
  等效边界刚度名义取 `STAGE_K_BASE`，1e4 N/m 量级。
- released：拨杆板向上抬起，两根销一起退出托架，托架只剩一根低刚度回复弹簧和
  一个硬止挡，边界走弹簧支路，名义刚度取 locked 的十分之一，1e3 N/m 量级。

两种状态都由硬限位确定，不靠摩擦力维持。locked 时拨杆板落座在框架顶面，销的插入
深度由销头台肩卡住；released 时拨杆板被定位柱塞顶在上止点，托架行程由止挡块限定为
`BND_TRAVEL` = 1 mm。每次切换回到同一止点，位置就一致。拨杆板升降高度在框架顶部
敞开处露出，高速视频能同时拍到拨杆位置和顶点运动，便于判断该帧属于哪个边界状态。

边界刚度的名义值属于工程估计，`locked` 与 `released` 的实际刚度和阻尼都要实测标定，
见 `params.PARAM_SOURCES` 的 `BND_TRAVEL` 条。销与孔的单边间隙会影响重复性，装配时
按实测间隙记录。

## 预载状态

`PRELOAD_MODULE` 用可换垫片堆设定预载，垫片总厚就是预载量，取值见
`params.PRELOAD_STATES`：

| 状态 | 预载 (mm) | 垫片片数 |
|---|---:|---:|
| P0 | 0.00 | 0 |
| P1 | 0.50 | 1 |
| P2 | 1.00 | 2 |
| P3 | 1.50 | 3 |

换一个状态只换垫片堆，不动其余模块，符合 §23.3 只扫少数关键变量的要求。0.5 mm
步距是工程估计，垫片厚度与滑块实际预压位移的对应关系需要实测标定。

## 关键尺寸与来源

| 尺寸 | 取值 | 来源 |
|---|---|---|
| 单级轴向 | 36.0 mm | §1.2 长度 30–50 mm 内 |
| 双级轴向 | 47.5 mm | §1.2 长度 30–50 mm 内，接近上限 |
| 横向 max(X,Y) | 22.0 mm | 由膜片压环外径 22 mm 决定，§1.2 内 |
| 浮动托架 | 16 × 10 × 4 mm | 工程估计，容两级底夹块 |
| 锁销直径 | 1.6 mm | 工程估计，受剪断面约 2.0 mm² |
| released 行程 | 1.0 mm | 工程估计，止挡块硬限位，待实测标定 |
| 预载步距 | 0.5 mm | 工程估计，待实测标定 |

## 装配顺序

1. 框架同 B/C 装好。
2. 把第一级底夹块装进 BOUNDARY_MODULE 的浮动托架，装两根 Y 向导柱。
3. 装 PRELOAD_MODULE 垫片座与所选垫片堆。
4. 装失稳单元。单级一个，双级两个串联，中间放级间垫片。
5. 装 OUTPUT 传力杆与膜片压环。
6. 装 RELEASE_MODULE 卡榫，扣住滑块台阶。
7. 插锁销并落拨杆板到 locked 止点，先跑 locked 组；再抬拨杆到 released 止点跑另一组。
8. 每组按预载状态换垫片，记录边界状态、预载、force-displacement、级序与膜片响应。

## 可拆可测性

弹性片、预载垫片、膜片都能单独换。锁销与拨杆在框架顶部敞开处，属于外露件，抽换
不用拆框架。托架可从侧面抽出做单独测量。浮动托架、锁销、预载顶块都可单独拆下，
符合 §22.1 的模块化与 §22.2 的可测试性。顶部敞开也让顶点运动与拨杆位置都能被拍到。

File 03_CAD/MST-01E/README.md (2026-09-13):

# MST-01E 自动供给完整版

## 目的

§13 的 E 级。在 D 级边界与预载之上再加 6–8 位旋转供给盘、索引机构与 Mode B 软载荷
通路，作为完整工程演示（§9、§12）。核心链仍有单级与双级两种，理由与 D 级相同，
见统一架构 §3.2 的模型预警。

## 模块与文件

- `build.py`：装配 FRAME、RELEASE_MODULE、BOUNDARY_MODULE、PRELOAD_MODULE、
  失稳单元（单级或双级）、OUTPUT、DIAPHRAGM_MODULE、MAGAZINE_MODULE 并自检。
- FRAME、RELEASE_MODULE、DIAPHRAGM_MODULE：与 B/C 同一套。
- BOUNDARY_MODULE、PRELOAD_MODULE：与 D 级同一套。
- MAGAZINE_MODULE：盘体、工位 pocket、盖板、中心轴、索引棘爪、零位标记、止挡柱。

## 供给盘布局

盘体绕 Z 轴，盘轴相对炮口轴线在 X 向偏置一个分布圆半径，正对炮口的工位落在 x=0。
分布圆半径由相邻座圈不干涉反算：`2·R·sin(π/N) >= 座圈外径 + 间隙`。位越多 R 越大，
盘径随之变大，这就是 §31 判断 8 位是否变大的几何来源。

| 盘位 | 分布圆 R (mm) | 盘径 (mm) | 分度角 | 整机包围盒 X×Y×Z (mm) | 件数 | 体积 (mm³) | 质量 (g) |
|---:|---:|---:|---:|---|---:|---:|---:|
| 6（单级） | 18.00 | 58.00 | 60.0° | 58.00 × 58.00 × 46.25 | 63 | 24756.4 | 36.95 |
| 8（单级） | 23.52 | 69.04 | 45.0° | 69.04 × 69.04 × 46.25 | 67 | 31179.4 | 44.35 |
| 6（双级） | 18.00 | 58.00 | 60.0° | 58.00 × 58.00 × 58.25 | 73 | 25634.2 | 38.57 |
| 8（双级） | 23.52 | 69.04 | 45.0° | 69.04 × 69.04 × 58.25 | 77 | 32057.2 | 45.97 |

8 位比 6 位盘径大 11.04 mm，约 19%，质量多约 7.4 g。按 §31「如果 8 位导致整体明显
变大，先 6 位」，建议第一版选 6 位，可靠后再上 8 位。轴向长度在 6 位单级下 46.25 mm，
仍在 §1.2 的 30–50 mm 内；双级加供给盘到 58.25 mm，超出长度上限 8.25 mm。

## 与 envelope 的对照

§1.2 的目标是核心脉冲模块长 30–50 mm、横向 15–25 mm，并注明加供给模块后允许略大。

- 轴向：单级 46.25 mm 在 30–50 mm 内；双级 58.25 mm 超出 8.25 mm。
- 横向：6 位 58.00 mm，超出上限 25 mm 达 33.00 mm；8 位 69.04 mm，超出 44.04 mm。

横向超出量很大，不能算「略大」。原因是一个对准炮口的 6 位转盘本身直径就接近 58 mm，
这是 16 mm 通径工位的固有尺寸，不是可以靠微调削掉的余量。核心模块（不含供给盘）仍是
D 级的 22 mm 横向，落在 envelope 内。若最终产品要压横向，需要改成炮口轴与盘轴不同面
的供弹方式或减少工位，超出本轮范围，这里只如实记录。

## 排除硬载荷的几何做法

§8.4 要求机械接口不能被无修改地装入 BB、钢珠、玻璃珠、陶瓷珠、金属柱、飞镖、尖头件。
pocket 用两重几何约束把它们挡在外面。

1. 工位 pocket 是环形座圈加中心通孔，座圈外径 16 mm、中心通孔直径 8 mm。软圆片直径
   14 mm，平铺时跨在座圈上。BB 和钢珠（4.5–6 mm）小于中心孔，直接漏下，装不住。
   直径大于 8 mm 的刚性球会落在座圈上，但球与座圈是点接触，球心高出座圈面，躺不平。
2. 盖板与软圆片顶面之间留固定间隙 `MAG_CLEAR` = 0.5 mm，总容高按软圆片厚 2 mm 定。
   金属柱、飞镖、尖头件比软圆片厚，装进 pocket 后会顶住盖板，索引转不到位，
   `INDEX_OK` 检测不通过，机构停在故障态而不是把它们发射出去。

两条约束合起来，只有薄而软的圆片能平躺通过，硬弹丸要么漏下要么卡住索引。中心孔的
直径与盖板间隙都要按最终软圆片实测厚度标定，见 `params.PARAM_SOURCES`。

## 防呆与零位

- 中心轴上有一个不对称的键 `MAGAZINE_key_boss`，轮毂上只有对应的键槽和一个插入
  方向，盘反装或转 180° 装不进，实现唯一方向防呆。
- 零位标记是随盘转动的遮光片 `MAGAZINE_zero_flag`，它对准第 0 工位。MCU 用光电
  或机械开关读它回到 HOME（§9.5），手动装回后重新回零即可。
- 机械止挡由 `MAGAZINE_stop_post` 与盘上凸台配合，限定最大转角，防止过转。
- 索引棘爪 `MAGAZINE_index_pawl` 在压簧作用下落在工位之间的分度槽，落槽即定位，
  一个槽对应一个工位。
- 可拔出：拆下轴端挡圈 `MAGAZINE_retainer`，盘沿 Z 从中心轴整体抽出。空盘人工更换，
  不做自动换盘（§9.4）。

## 关键尺寸与来源

| 尺寸 | 取值 | 来源 |
|---|---|---|
| 盘位 | 6 / 8 | §9.1；§31 8 位变大则先 6 位 |
| 软圆片直径 | 14 mm | §8.1，略小于 16 mm 通径，待实测标定 |
| 软圆片厚度 | 2 mm | §8.1，工程估计，待实测标定 |
| pocket 中心孔 | 8 mm | §8.4，硬珠漏下 |
| 座圈外径 | 16 mm | 工程估计，对应通径量级 |
| 相邻座圈间隙 | 2 mm | 工程估计，避免 8 位相邻干涉 |
| 盖板间隙 | 0.5 mm | §8.4，厚度防呆，待实测标定 |
| 分度角 | 60° / 45° | 360° / 盘位 |

## 装配顺序

1. 框架同 B/C 装好，失稳单元、边界、预载、释放同 D 级。
2. 装膜片压环。
3. 把软圆片逐片放进各工位座圈，装索引盖板。
4. 盘体套上中心轴，对准防呆键装到底，装轴端挡圈。
5. 装索引棘爪与压簧，装止挡柱。
6. 手动盘转，确认棘爪逐工位落槽、零位遮光片能被传感器读到。
7. 装回零位，跑一次 INDEX 循环确认 `INDEX_OK`。

## 可拆可测性

供给盘整体可抽出做独立实验（§18），工位件数与盘径都能单独测。每个 pocket 独立约束，
软圆片不会像直线弹匣那样叠片卡住（§9.3）。边界与预载模块同 D 级，仍可单独拆测。
顶部敞开，索引动作与顶点运动都能拍到。核心脉冲模块横向 22 mm 仍在 envelope 内，
加供给盘后的横向超出量见上一节。

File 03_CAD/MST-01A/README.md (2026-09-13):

# MST-01A 普通膜片基线

## 目的

§13 的 A 级。没有 snap-through，低速执行器直接推膜片，用来建立力－位移与空气脉冲的基线。
后面 B、C 的改善量都以这一级为分母。

## 模块与文件

- `build.py`：装配 FRAME、ACTUATOR、DIAPHRAGM_MODULE，跑几何自检。
- FRAME：后盖板、底板、两片侧壁、前端压边、两个安装凸台。
- ACTUATOR：低速执行器本体加一根推杆，直接顶膜片中心。
- DIAPHRAGM_MODULE：膜片加前后两片可拆压环，四颗 M2 螺钉。

A 级无储能元件，按 §13 不需要释放卡榫，所以没有 RELEASE_MODULE。

## 关键尺寸与来源

| 尺寸 | 取值 | 来源 |
|---|---|---|
| 框架外廓 | 20 × 18 mm | §1.2 横向 15–25 mm 内取值 |
| 轴向长度 | 32 mm | §1.2 长度 30–50 mm 内，随级递增 |
| 侧壁厚 | 1.6 mm | 工程估计，0.4 mm 喷嘴约 4 圈 |
| 膜片夹持半径 | 8 mm | 对齐 `04_SIMULATION/models/params.py`，§1.2 量级 |
| 膜片通径 | 16 mm | 2 × 夹持半径 |
| 压环外径 | 22 mm | 工程估计，夹持半径加 3 mm 环边 |
| 推杆直径 | 3 mm | 工程估计，够刚且能顶膜片中心 |

膜片厚度取 0.2 mm 硅胶，与仿真候选 A 一致，材料常数待实测标定。

## 装配顺序

1. 后盖板与两片侧壁、底板对插，点胶或热熔定位。
2. 执行器本体固定在后盖内，推杆朝向 +Z。
3. 后压环套上膜片，膜片贴住前端，再压上前压环。
4. 四颗 M2 螺钉对角渐进拧紧，压边夹在框架前端。
5. 推杆前端对准膜片中心，留出小预压。

## 可拆可测性

换膜片只拆压环四颗螺钉，框架不动。执行器本体可整体取出。顶部敞开，推杆与膜运动可用
普通相机或高速视频拍到。轴向长度 32 mm、横向 22 mm，落在 §1.2 envelope 内。

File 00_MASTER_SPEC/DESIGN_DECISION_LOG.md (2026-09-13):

# MST-01 设计决策日志（DESIGN_DECISION_LOG.md）

本文件对应主规格 §32 TASK-05 与 §33 交付项，记录第二期机械核心与系统架构已经做出的决策。
每条按 decision / reason / alternative / evidence / validation / failure condition 六个字段写，
字段用中文标题。`备选方案` 一栏要写清反对意见，即被否方案为什么不行，这是这份日志的主要用途。

决策来源限定在规格书与统一架构方案已有内容，本文件不新增方案。引用用章节号与 REQ 编号，
例如 §5.3、架构 §6.6、REQ-083。需求编号对应 `02_REQUIREMENTS/REQUIREMENTS.md`。

成本口径按 `06_BOM/bom.csv`：计入 ¥50 的只有炮头机械架构，MCU、舵机、电源、PCB、打印材料不计入。

---

## D-01 把两级串联失稳加膜片冻结为工程基线

- 决策：第二期机械核心采用「低速预载 → 两级串联失稳 → 直接机械耦合柔性膜片 → 瞬态低能量空气脉冲」。
  先交付 Mode A 纯空气版，再加 Mode B 软载荷与供给盘。
- 理由：尺寸落在 §1.2 的 envelope 内；成本落在 §21；A/B 对照容易做；输出有明确可测的力学变量；
  可以回答「多级失稳对脉冲波形是否真有价值」这个研究问题。哪怕最终专利新颖性不足，也能留下机械研究数据（§3）。
- 备选方案：把「串联 snap 加可切换边界」当成新颖核心直接展开。
  反对意见：SRC-04（Santos 2026）已经公开 2–4 个 von Mises truss 单元串联、sliding support 可锁可释放、
  engagement gap 调节响应；SRC-01/02/03 已覆盖 sequential snap 与顺序可调。按 §2.2，这条不能再当新颖性核心，
  只能当研究变量。把它包装成首创会在评审和查新时直接站不住。
- 依据：§3、§2.2、[SRC-01] 到 [SRC-04]；REQ-070 到 REQ-075；REQ-133。
- 验证方式：A1/B1/C1 的动态数据，看能否拿到可重复的 force-displacement 与脉冲时间曲线（§16、§35）。
- 失效条件：STOP-01（单级相对普通膜片无可测优势）或 STOP-02（双级更差）。命中即按架构 §6.8 关闭双级分支。

---

## D-02 保留 A/B/C 单级对照

- 决策：A（普通慢推膜片）、B（单级 snap）、C（双级 snap）三个原型都做，不得跳过。
- 理由：已有研究证明多级可以形成复杂 force-displacement，但这推不出它对微型膜片空气脉冲有好处（§5.3）。
  缺了对照，出问题时无法判断来自 snap、膜片、第二级还是集成（§14）。
- 备选方案：直接做双级，或先做完整版 E。
  反对意见：一旦结果不理想就归因不了，等于把可回答的研究问题变成不可回答。SRC-05 还提示弹性能转流体有损失，
  不能预设 snap 效率更高。省掉对照省的是时间，赔的是整个实验的解释力。
- 依据：§5.3、§14、[SRC-05]；REQ-074、REQ-108、REQ-109。
- 验证方式：三级在同一测试台上对照，变量按 §15 记录。
- 失效条件：不因结果撤销。对照是执行纪律。若 B/C 有数据而 A 缺失，这批数据不能用于归因，必须补齐。

---

## D-03 供给用旋转盘，不用直线弹匣

- 决策：供给采用 6–8 位旋转盘，每片载荷有独立 pocket。8 位使整体明显变大时先做 6 位。
- 理由：软圆片在狭长通道里容易翘曲、摩擦、叠片、卡住；旋转盘每个位置独立约束，第一版优先可靠性（§9.3、§8.2）。
- 备选方案：直线弹匣。
  反对意见：通道长，软片易叠片、卡料，可靠性验证成本更高。供给本身已有明确专利（PAT-03/04/05），
  在这个环节冒可靠性风险换不到任何研究价值。
- 依据：§9.1、§9.3、§8.2、§31；REQ-094、REQ-097、REQ-151；[PAT-03] 到 [PAT-05]。
- 验证方式：M1 独立 50 次索引，人工复位不超过 1 次。
- 失效条件：STOP-04，50 次人工复位超过 1 次。

---

## D-04 主载荷用 EVA/EPP 圆片，不用球

- 决策：主载荷为 EVA 或 EPP 超轻软质圆片。
- 理由：能平铺在盘内、不自由滚动、每个位置可独立约束、供给通道短、弹仓厚度低、密度低、颜色可做状态识别、
  易冲切（§8.2），与旋转盘接口配合也顺。
- 备选方案：软球。
  反对意见：球在盘里会自由滚动、互相堆叠，无法保证每发位置确定。要防滚动得加深腔或加盖，弹仓变厚，
  与小型化直接冲突；而且位置不确定会让 INDEX_OK 判定失去意义。§8.1 已明确主方案不用球。
- 依据：§8.1、§8.2；REQ-089、REQ-090、REQ-091。
- 验证方式：M1 与 Mode B 集成测试中记录双片、错位、卡料。
- 失效条件：圆片在盘内仍翘曲或约束不稳，换材料与压环后也解决不了，则重评 pocket 几何，或退回毛毡、纸片（§8.3）。

---

## D-05 膜片用可拆压环，不用永久胶粘

- 决策：膜片用可拆压环固定。
- 理由：换材料、查损伤、做 A/B 对照都方便。胶层厚度与固化程度会变成隐藏变量，压环把它变成可重复的夹紧方式（§6.3）。
- 备选方案：永久胶粘。
  反对意见：换一次膜就破坏一次装配，胶层批次差异混进力学数据。膜片正是第一批要比较的变量
  （§6.2 要求至少比较弹性体膜与聚酯膜），胶粘会让对照失真。
- 依据：§6.3、§6.2；REQ-083、REQ-081、REQ-128。
- 验证方式：多次拆装后气密性与夹紧力是否稳定；A1 压力曲线在复装后是否一致。
- 失效条件：压环在小型化后夹不紧，或改变了膜片边界条件导致重复性变差，则改结构但保留可拆属性。

---

## D-06 打印件只做框架，弹性元件独立

- 决策：打印件承担框架、支撑、限位、边界切换、模块定位；snap 主变形交给独立弹性元件，
  PET 做几何验证，弹簧钢做寿命与重复性版。
- 理由：FDM 层间性能波动、疲劳寿命不稳、缩小后误差比例放大。把高循环失稳核心全交给打印柔性梁，
  寿命和重复性都难控（§7.1）。独立弹性片性能可测、可换。
- 备选方案：全部一体打印。
  反对意见：看着省件，实际把材料批次差异和疲劳混进设计变量，无法分离。换弹性特性要重打印整体件，
  违反 §22.2 可拆可测。§22.3 也明确第一版不许追求全部一体打印。
- 依据：§7.1、§7.2、§22.2、§22.3；REQ-084 到 REQ-088。
- 验证方式：A/B/C 的重复性与 §17 寿命阶梯，对比不同弹性件。
- 失效条件：PET 件进入寿命测试后出现明显蠕变或漂移，则切弹簧钢；弹簧钢也无稳定寿命，则重评失稳方案。

---

## D-07 执行机构改成微型舵机，删除电机闭环

- 决策：第二期云台用微型舵机位置指令，删除 motor_driver、encoder、axis 与双环 PID，
  保留 angle_utils 和 PID 限幅部分。
- 理由：执行机构从 12V 减速电机改成舵机后释放 11 个 GPIO，引脚预算翻转，单片 MCU 够用；舵机自带位置闭环，
  省掉编码器与驱动电路。代价是失去低速平滑与基于实测角速度的提前量收敛，这个代价接受（架构 §7）。
- 备选方案：继续用电机加编码器闭环。
  反对意见：占用引脚多、体积与功耗大，直接逼回双 MCU；火柴盒级产品多一块板多一份体积和故障面（架构 §3.1）。
  编码器带来的精度提升对低能量近距离平台不构成决定性收益，却要把体量和复杂度拉上去。
- 依据：架构 §3.1、§7、§6.10；REQ-155、REQ-156；附录 C-02。
- 验证方式：MST-01A 阶段量静态指向重复性（架构 §9.2）；多次上电测零位散布（架构 §6.11.3）。
- 失效条件：开环指向精度无法把目标锁在画面死区内，参考开关上电校验也补不回来，则重评执行机构。

---

## D-08 状态机做成双区域，不拉平成单一枚举

- 决策：状态机分区域 A（发射周期，11 态）与区域 B（指向质量，6 态），各有转移表，跨区用守卫矩阵约束。
- 理由：两件事天然并发，PRELOAD 期间可以仍处于 TRACKING，READY 期间也可以处于 SEARCHING。
  压成单个枚举会得到 11×7 的笛卡尔空间，其中绝大多数组合非法；用扁平枚举等于用缺席表达非法，
  漏判一处就进入不可能状态。发射链是安全相关代码，靠人工维护合法性矩阵最容易出错（架构 §6.1）。
- 备选方案：扁平单枚举。
  反对意见：合法性维护成本高，扩展时要把整个枚举重排一遍；非法组合没有显式拦点。双区域把非法组合
  收敛进守卫矩阵，扩展时只动矩阵。
- 依据：架构 §6.1、§6.2；REQ-054、REQ-055、REQ-056；附录 C-03。
- 验证方式：状态机单元测试覆盖守卫矩阵每个格子；上电与故障恢复流程走查。
- 失效条件：守卫矩阵本身引入死锁（比如标定态无法退出），修订矩阵。区域划分不撤销。

---

## D-09 单片 MCU 加 I2C 扩展，不用双 MCU

- 决策：第二期用单片 ESP32-S3，慢速离散 I/O 走 MCP23017（I2C0），快速信号直连 GPIO。
- 理由：电机闭环删除后释放 11 个 GPIO，引脚够用。单片省一块板的体积、功耗和成本；没有跨 MCU 协议，
  就没有协议失配、版本不一致、通信超时这三类故障；RELEASE 到膜片的时序留在片内，不受总线延迟影响（架构 §3.1）。
- 备选方案：双 MCU（视觉板加炮头板）。
  反对意见：多一块板加一条跨片协议，等于给一个不可逆动作引入额外通信失败面。火柴盒级产品放不下这个复杂度，
  而引脚预算已经不再是瓶颈。
- 依据：架构 §3.1、§4、§4.3；REQ-161；附录 C-09。
- 验证方式：实测最坏情况下 PRELOAD/RELEASE 的时序抖动（架构 §9.1）；引脚逐条对照实物原理图（架构 §4.5）。
- 失效条件：视觉处理导致发射时序抖动超标，非阻塞任务隔离也压不下去，则重评是否把发射时序外移。

---

## D-10 释放门控必须硬件实现

- 决策：释放能量路径由物理与门树、负载开关和单稳态实现，软件只作第一道闸与诊断。
- 理由：§10.4 禁止用软件时序替代机械互锁。释放不可逆，软件卡死或输出错误电平时必须还有硬件兜底。
  与门树 Q1/Q2 串在供电回路，输入开路即安全侧；单稳态把驱动时间上限钳死；低边 N-MOSFET 栅极带下拉（架构 §6.6）。
- 备选方案：只用 GPIO 直写释放。
  反对意见：MCU 卡在输出高会持续通电，软件 bug 直接变成物理动作。现有 transmitter.cpp 就是这个写法，
  架构 §6.9 第 4 条已经把它列为冲突项。
- 依据：§10.4、§11 Interlock 3；架构 §6.5 H1、§6.6、§6.11.1；REQ-062、REQ-063、REQ-067。
- 验证方式：搭只有释放链和与门的小板，逐条故意断开输入、故意让 MCU 输出常高，确认释放无动作（架构 §6.11.1）。
- 失效条件：与门树在火柴盒体积内落不下，或断线时不能可靠落到禁止侧。命中则暂停后续状态机工作，先解决 H1。

---

## D-11 参考开关不能省

- 决策：每轴保留 PAN_HOME、TILT_HOME，供给盘保留 MAG_HOME，归零失败进 FAULT。
- 理由：上电前被外力拨偏、装配偏差都真实存在；释放不可逆，一次基准错误就是打错方向。舵机内部虽然位置闭环，
  但绝对角基准仍依赖装配，参考开关用来验证装配基准（架构 §6.10）。
- 备选方案：只靠舵机指令脉宽的绝对角，省掉开关。
  反对意见：PWM 舵机的绝对角来自内部电位计，装配偏差和外力拨偏都测不出来，开环后也没有第二来源。
  总线舵机虽然能回报位置，但省掉开关后连装配基准对不对都无法校验。
- 依据：架构 §6.10；REQ-157、REQ-156；附录 C-06。
- 验证方式：多次上电测零位散布；故意把舵机拨偏后上电，确认能回到基准；检验 3 秒超时判据是否合适。
- 失效条件：参考开关重复定位精度不足或容易卡滞（见 FM-01），则改冗余开关，或改总线舵机位置加校验开关。

---

## D-12 优先总线舵机，PWM 舵机降级

- 决策：云台优先选带总线反馈的舵机，经典三线 PWM 舵机作为降级选项。
- 理由：§1.1 已把云台舵机排除在 ¥50 之外，预算不是约束。总线舵机能回报位置、负载、温度，
  把失速检测从猜变成读，PAN_HOME、TILT_HOME 也退化成一次上电校验（架构 §6.10）。
- 备选方案：只用经典 PWM 舵机。
  反对意见：没有负载与位置反馈，只能靠电流和到位时间间接判失速，判据容易误报漏报；参考开关从校验角色
  变成唯一基准，可靠性要求反而更高。省下的钱不进 ¥50 口径，换不到收益。
- 依据：架构 §6.10；REQ-156、REQ-158。
- 验证方式：候选舵机做定角阶跃、记录电流波形、标定堵转阈值，确认「电流超限且持续」不误报不漏报（架构 §6.11.3）。
- 失效条件：总线舵机成本、体积或供货不合适，或总线启动延迟影响归零时序，则退回 PWM，并强化参考开关与电流式失速检测。

---

## 决策与 STOP 条件对照

| 决策 | 相关 STOP | 命中后动作 |
|---|---|---|
| D-01、D-02 | STOP-01、STOP-02 | 关闭双级分支或回退单级，记录到 10_FAILURE_ANALYSIS |
| D-03 | STOP-04 | 先修供给，不与炮头集成 |
| 全部涉及机械成本 | STOP-05 | 按 §21 顺序砍件，不得删安全与状态检测项 |

## 未决项

- ARMED 态能否安全卸载（架构 §6.11 末）。这条决定状态机可用性，没有定论，A/B/C 阶段一并验证。
  在结论出来前，ARMED 期间的任何中止按锁 FAULT 加硬件断开来处理。

---

## D-13 释放执行器采用机械自锁加电磁铁拔销

- 决策：释放执行器以机械自锁保持。卡榫由弹簧保持啮合，只有给电磁铁通电才拔销释放；
  掉电、断线、MCU 输出错误电平都不改变啮合状态。
- 理由：失效方向落在安全侧。掉电即不释放，与统一架构 §6.7 对 `FIRE_INHIBIT`、`EXTERNAL_ALLOW`
  的 fail-safe 要求同一方向，都是未主动施加能量就不许可动作。自锁保持不耗电，ARMED 期间可以
  长时间保持储能，§6.11 末的 ARMED 卸载未决项也多一条可选路径。
- 备选方案：通电保持、掉电释放。
  反对意见：断电时把预载储能直接打出去，失效方向与安全侧相反，与 §6.7、§10.4 的约定冲突，
  不能作为释放方案。
- 备选方案：记忆合金或熔断丝一次性释放。
  反对意见：动作后不可复位，与 §9.2 的逐发循环和 §17 的循环寿命阶梯（REQ-118，100/500/1000 次）
  冲突，每次发射都要换件，连续实验做不了。
- 备选方案：直接由舵机反向卸载。
  反对意见：舵机卸载行程慢，产生不了释放所需的瞬态脉冲，与 §5 的脉冲整形目标不符，
  只能当辅助手段。
- 依据：统一架构 §6.7、§6.5 H1、§10.4；§9.2、§17；REQ-063、REQ-067、REQ-118。
- 验证方式：对照释放链板级步骤（架构 §6.11.1；`03_CAD/electronics/test-procedure.md`）
  逐条断输入、故意让 MCU 输出常高，确认释放无动作；再单独验证给电磁铁通电时能可靠拔销，
  断电时卡榫保持啮合。
- 失效条件：若弹簧保持力不足以抵抗预载反力，或电磁铁吸力不足在振动下无法拔销，
  该方案作废，回到备选评估。

---

## D-14 双级串联是否保留，等 B1/C1 实验裁决

- 决策：暂不改变 D-01 的工程基线，双级串联继续按第二期机械核心推进，同时把它标为「模型存疑、待实验裁决」。
  在 B1、C1 数据出来前，不把双级当已定结论写进论文或冻结选型。实测复现模型的倾向就按 STOP-02 回退单级；
  实测给出实质增益就保留，并回头查模型假设。
- 理由：`04_SIMULATION/` 的纯软件模型（准静态、瞬态、参数扫描）给出两组互相拉扯的结果。倾向回退的一面：
  名义参数下 C 相对 B 的膜片峰值速度只高约 18%（模型 10.573 对 8.939 m/s），输入功接近翻倍
  （模型 37.623 对 19.963 mJ）；C 的两级事件顺序不稳定，刚度失配 k_bar2/k_bar1 到 1.5 倍即从 (1,0) 翻为 (0,1)，
  级间间隔在模型里于 2.32 到 7.20 ms 之间漂移；模型准静态下两级各距 fold 只有 0.008 mm，几乎同时跳变，
  静态分不出先后。倾向保留的一面：模型里单级相对普通膜片本身有明显增益（B 对 A 峰值速度 8.939 对
  0.469 m/s，约 19.1 倍），双级在名义点仍有 18% 的可测差异。按 §30 STOP-02 的三个分句，模型只让
  「更不稳定」成立，「响应没有区别」不成立，「寿命下降严重」尚未测（§17 的 100/500/1000 阶梯没做）。
  三点合起来是边缘判定，不够干净命中 STOP-02，因此当前只能记录倾向，不能据此拍板。
- 备选方案：现在按模型倾向回退单级，冻结单级方案。
  反对意见：模型的关键输入 `k_bar` 没有实测，`04_SIMULATION/models/params.py` 自己把它标为等效参数、
  待实测标定；膜片按线弹性处理，硅胶粘弹滞后未建模；摩擦、重力、气压反作用与流体耦合被忽略；作动器理想化。
  任何一条失真都可能改写双级那 18% 的增益，流体耦合缺失还直接落在真正关心的空气脉冲效率上。
  「更不稳定」也依赖未标定的刚度失配。用这样的模型替 STOP-02 定案，等于让一个没有实测支撑的计算去否决一条工程基线。
- 依据：§30 STOP-02、§16、§17、§23、§14；D-01、D-02；REQ-143；`04_SIMULATION/README.md` 的初步结论与
  `04_SIMULATION/results/` 下的 transient_summary.csv、sweep_mismatch.csv、boundary_sensitivity.csv。
- 验证方式：B1 与 C1 的动态数据。B1 看单级相对普通膜片是否有可测优势（对应 STOP-01）；C1 看两级事件是否可分辨、
  顺序是否固定、inter-stage delay 是否稳定，以及相对 B1 是否有工程价值。寿命按 §17 补 100/500/1000 阶梯，
  把 STOP-02 里没测的分句补上。TEST_PLAN 的 B1、C1 通过标准处已写入模型先验预测，作为要证伪或证实的对象。
- 失效条件：C1 实测复现模型倾向且寿命指标也下降，按 STOP-02 回退单级，记录到 10_FAILURE_ANALYSIS。
  若 C1 显示双级有实质增益，与模型预测相反，则判模型在当前假设下失效，优先核查 `k_bar` 标定、膜片粘弹、
  流体耦合三项，修订模型后重新解释数据，不据此改动基线。

---

## D-15 供给盘位数与尺寸目标冲突的处置（待裁决）

- 决策：暂不改变 D-03 的旋转盘方向，也暂不冻结 Mode B 的整机尺寸。当前状态是记录一个项目级几何冲突：
  按当前载荷尺寸与位数，供给模块与 §1.2 的尺寸目标冲突，§1.2 允许的「略大」不足以覆盖，需一并裁决。
  裁决前，6 位与 8 位都按超 envelope 处理，不写成满足 §1.2。
- 理由：`03_CAD/MST-01E` 的几何自检（非实测）给出包围盒：单级加 6 位供给盘 58.00 × 58.00 × 46.25 mm，
  单级加 8 位 69.04 × 69.04 × 46.25 mm，双级加 6 位 58.00 × 58.00 × 58.25 mm，双级加 8 位 69.04 × 69.04 × 58.25 mm。
  供给盘之外的核心模块横向仍是 22 mm，在 envelope 内；装盘后横向超出上限 33.00 mm（6 位）到 44.04 mm（8 位），
  轴向双级配置也超出 8.25 mm。超出由几何约束决定，与建模误差无关：软圆片直径 14 mm 时，
  6 位需要分布圆半径 18 mm、8 位需要 23.52 mm，相邻座圈不干涉条件 `2R·sin(π/N) ≥ 座圈外径 + 间隙`
  决定位数越多半径越大。这是 CAD 几何结论，不是实验结论。
- 备选方案：
  - 缩小载荷直径（14 mm 改小），重新核算位数与盘径。代价：软圆片的约束、气动与供给行为都会变，
    §8.2、§9.3 的既有论证要重做，基于 14 mm 的实验数据可能作废。
  - 减到 4 位或更少。代价：弹仓容量下降，Mode B 的连续索引与自动换弹验证样本变少，
    §9.2 的供给序列实验次数与统计意义都缩水。
  - 接受 Mode B 整机变大，只在 Mode A 保持火柴盒级。代价：放弃整机小型化口径，
    §1.2 对 Mode B 不再成立，论文与专利表述要把两种模式分开；供给盘之外的模块不受影响。
  - 换供给方式（直线弹匣等）。代价：要正面处理 §9.3 已论证的直线通道卡料问题，
    软片叠片、翘曲、摩擦的可靠性风险上升，换不到研究价值。
  - 把供给盘做成可拆卸的独立模块，只在装盘时占用额外体积。代价：增加接口与定位件，
    §9.5 的可拔出、防呆、零位、手动装回后重新 HOME 都要重新验证；体积并未真正消失，只是不常驻。
- 依据：§1.2、§9.1、§9.3、§31；REQ-026、REQ-027、REQ-094、REQ-151、REQ-152；D-03；
  `03_CAD/MST-01E/` 的几何自检（非实测）。
- 验证方式：裁决前需要的数据与动作：按候选方案重算盘径与包围盒；量载荷直径缩小后软片的约束与供给行为；
  4 位方案的容量与索引统计；可拆卸供给盘的接口与重复定位验证。CAD 自检只能证明几何冲突，
  不能替尺寸目标与位数的取舍定案。
- 失效条件：任一候选方案经核算或验证后仍落在 envelope 外，且无法用「略大」解释，则退回本条目重评；
  若最终确认 6 位与 8 位都无法与尺寸目标共存，则按 §1.1 优先级（小型化排在可靠性之后）重新权衡位数与整机口径。

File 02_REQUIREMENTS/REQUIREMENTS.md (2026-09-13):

# MST-01 需求规格（REQUIREMENTS.md）

本文件对应主规格 §32 TASK-01 与 §33 交付项。需求从
`00_MASTER_SPEC/MST-01_Offline_Agent_Master_Spec_v2.0.md` 提取；凡与规格书叙述冲突处，
按 `00_MASTER_SPEC/统一架构方案.md` 的已冻结裁决处理，裁决结果在第三部分列出。

## 文档约定

- 需求编号 `REQ-nnn` 全局唯一，按主题分组连续编号。
- 类型含义：
  - `MUST`：必须满足，验收不通过即缺陷。
  - `MUST NOT`：禁止项。
  - `SHOULD`：建议；偏离时需在 `DESIGN_DECISION_LOG.md` 记录理由。
  - `MAY`：允许项，不作为强制验收。
- 来源写章节号，如 §11 Interlock 3，便于回溯。
- 需求正文按可验收方式重写，不照抄规格书叙述。

---

## 1. 项目定义与用途纪律

| 编号 | 类型 | 需求 | 来源 |
|---|---|---|---|
| REQ-001 | MUST | 交付物是一台 MCU 可控制、火柴盒级、低能量、可模块化供给超轻软载荷的二维指向式快速机械脉冲执行平台。验收看三项实体齐备：二维指向机构、机械脉冲核心、可选供给模块，全部由同一套 MCU 管理。 | §0.1、§3、§4 |
| REQ-002 | MUST NOT | 不得以蚊虫或任何生物作为目标或应用场景；设计、实验与文档中不得出现翼频检测、Photonic Fence、蚊虫分类、目标生物特性。 | §0.1、§2.1、§34、§38 |
| REQ-003 | MUST NOT | 不得把装置定义为以伤害、穿透、最大射程或高速度为目标的武器系统。工程称谓统一为定向低能量脉冲平台。 | §0.2 |
| REQ-004 | MUST NOT | 不得以高功率激光、火药、高压气瓶、硬质弹丸作为替代实现方案。 | §34、§0.3 |
| REQ-005 | MUST NOT | 不得为了外观像炮而牺牲研究可测性。 | §34 |
| REQ-006 | MUST NOT | 不得为了显得创新而增加没有实验价值的复杂机构。 | §34 |
| REQ-007 | MUST | 参数或方案冲突时，按 安全 > 可重复性 > 可靠性 > 小型化 > 低成本 > 输出强度 的固定优先级裁决，不得临时调换顺序。 | §0.3、§39 |

---

## 2. 安全边界与禁止项

| 编号 | 类型 | 需求 | 来源 |
|---|---|---|---|
| REQ-008 | MUST | 允许的输出类型限于纯空气脉冲与超轻软载荷；实验限于低能量近距离封闭环境。 | §0.3 |
| REQ-009 | MUST | 允许 EVA、EPP、毛毡、轻纸质等超轻软载荷，主载荷为 EVA 或 EPP 圆片。 | §0.3、§8.1 |
| REQ-010 | MUST NOT | 禁止金属弹丸。 | §0.3 |
| REQ-011 | MUST NOT | 禁止玻璃弹丸与陶瓷弹丸。 | §0.3 |
| REQ-012 | MUST NOT | 禁止硬质高密度实心塑料弹丸。 | §0.3 |
| REQ-013 | MUST NOT | 禁止针、箭、飞镖及任何尖锐载荷。 | §0.3 |
| REQ-014 | MUST NOT | 禁止火药、爆燃、燃烧推进。 | §0.3 |
| REQ-015 | MUST NOT | 禁止高压储气瓶。 | §0.3 |
| REQ-016 | MUST NOT | 不得把提高伤害、穿透或最大射程作为优化目标。 | §0.3、§15.3 |
| REQ-017 | MUST NOT | 不得进行人体或动物测试。 | §0.3 |
| REQ-018 | MAY | 允许机构动力学、顺序失稳、脉冲整形研究，以及自动索引供给与 MCU 状态控制。 | §0.3 |

---

## 3. 成本边界

| 编号 | 类型 | 需求 | 来源 |
|---|---|---|---|
| REQ-019 | MUST | ¥50 预算只约束炮头机械架构本体，不约束整机。 | §1.1 |
| REQ-020 | MUST | 计入 ¥50 的项目为：弹性片、柔性膜片、轴/销/铜套/小轴承、O 型圈与密封件、磁铁、紧固件、低密度软载荷、非打印小型机械件。 | §1.1 |
| REQ-021 | MUST NOT | 以下不得计入 ¥50：MCU、主控板、传感器后台、云台舵机、云台电机、发射/蓄能的外部执行电机或舵机、电源、PCB、线材、通信模块、3D 打印材料成本、CAD/仿真/实验仪器成本。 | §1.1 |
| REQ-022 | MUST NOT | 不得为了省 MCU、舵机或打印材料而破坏机械方案。检验方式：每处成本削减都要确认没有削弱机械架构的可靠性。 | §1.1 |
| REQ-023 | MUST | 炮头机械架构 BOM 推荐不超过 ¥40，硬限制小于 ¥50。 | §21 |
| REQ-024 | MUST | 超预算时按序削减：非必要轴承，CNC/金属定制件，多余装饰壳，不必要传动级。 | §21 |
| REQ-025 | MUST NOT | 成本削减不得删除状态检测、防脱结构、必要密封、安全互锁。 | §21 |

软载荷属耗材，首次配备计入 ¥50，后续更换不计入 BOM 目标（REQ-020 的边界补充，归类待确认，需在 `DESIGN_DECISION_LOG.md` 记录）。

---

## 4. 尺寸 envelope

| 编号 | 类型 | 需求 | 来源 |
|---|---|---|---|
| REQ-026 | MUST | 尺寸目标为尽可能小同时保持可靠，整体属于火柴盒/掌心级，不设冻结毫米值。 | §1.2 |
| REQ-027 | SHOULD | 核心脉冲模块长度取 30–50 mm 级，横向尺寸取 15–25 mm 级，加供给模块后允许略大。 | §1.2 |
| REQ-028 | MAY | 仿真若显示放大 10–20% 能显著提升可靠性，可先做可靠原型再缩小。 | §1.2 |

---

## 5. 控制原则

| 编号 | 类型 | 需求 | 来源 |
|---|---|---|---|
| REQ-029 | MUST | MCU 控制状态，快速机械动作由机械结构产生；不得让 MCU 直接产生高速机械动作。 | §1.3 |
| REQ-030 | MUST | MCU 功能覆盖归零、瞄准接口、预载状态、边界状态、触发许可、状态检测、供给索引、故障锁定、循环计数、日志。 | §1.3 |
| REQ-031 | MUST NOT | 不得用软件时序替代机械互锁。 | §10.4 |
| REQ-032 | MUST NOT | 不得在机构状态未知时重复触发。 | §10.4 |
| REQ-033 | MUST NOT | 不得在机构未复位时索引供给盘。 | §10.4 |
| REQ-034 | MUST NOT | 不得把输出强度当作无限制可调参数。 | §10.4 |

---

## 6. MCU 逻辑输入

逐个列出 §10.2 要求的输入信号。每条都要求预留，实现方式可由 Hall、光电、微动、参考开关等承担（编码器与电机电流的用法另见第三部分 C-06）。

| 编号 | 类型 | 信号 | 含义 | 来源 |
|---|---|---|---|---|
| REQ-035 | MUST | `PAN_HOME` | pan 轴物理零位参考。 | §10.2 |
| REQ-036 | MUST | `TILT_HOME` | tilt 轴物理零位参考。 | §10.2 |
| REQ-037 | MUST | `MAG_HOME` | 供给盘零位。 | §10.2 |
| REQ-038 | MUST | `MAG_INDEX_OK` | 供给盘索引到位确认。 | §10.2 |
| REQ-039 | MUST | `STAGE1_STATE` | Stage 1 失稳事件状态。 | §10.2 |
| REQ-040 | MUST | `STAGE2_STATE` | Stage 2 失稳事件状态。 | §10.2 |
| REQ-041 | MUST | `MECH_RECOVERED` | 机械核心复位确认，Interlock 1 的唯一依据。 | §10.2 |
| REQ-042 | MUST | `FIRE_INHIBIT` | 安全否决输入，置位时禁止释放。 | §10.2 |
| REQ-043 | MUST | `EXTERNAL_ALLOW` | 上级释放许可输入。 | §10.2 |

---

## 7. MCU 输出

逐个列出 §10.3 要求的输出信号。

| 编号 | 类型 | 信号 | 含义 | 来源 |
|---|---|---|---|---|
| REQ-044 | MUST | `PAN_CMD` | pan 轴位置命令。 | §10.3 |
| REQ-045 | MUST | `TILT_CMD` | tilt 轴位置命令。 | §10.3 |
| REQ-046 | MUST | `BOUNDARY_CMD` | 边界状态切换命令。 | §10.3 |
| REQ-047 | MUST | `PRELOAD_CMD` | 预载命令。 | §10.3 |
| REQ-048 | MUST | `RELEASE_CMD` | 释放命令。 | §10.3 |
| REQ-049 | MUST | `MAG_INDEX_CMD` | 供给盘索引一步命令。 | §10.3 |
| REQ-050 | MUST | `STATUS_LED` | 状态指示输出。 | §10.3 |
| REQ-051 | SHOULD | `DEBUG_TX` | 调试串行输出，映射到 UART0 或 USB CDC（归类待确认，见 C-10）。 | §10.3 |

---

## 8. 状态机

| 编号 | 类型 | 需求 | 来源 |
|---|---|---|---|
| REQ-052 | MUST | 主状态序列为 BOOT → SAFE → HOME → READY → AIM_ALLOWED → PRELOAD → ARMED → RELEASE → RECOVER → INDEX → READY。 | §10.1 |
| REQ-053 | MUST | 任意状态发生异常时进入 FAULT，FAULT 之后回到 SAFE。 | §10.1 |
| REQ-054 | MUST | 状态机分为发射周期区与指向质量区两个区域，各自维护转移表，跨区用守卫矩阵约束；不得压平为单一枚举表达全部组合。 | §10.1，统一架构 §6.1（裁决） |
| REQ-055 | MUST | `AIM_ALLOWED` 在指向质量区处于 `LOCKED` 时授予，`LOCKED` 是持续评估的质量谓词，不是一次性事件。 | 统一架构 §6.2 |
| REQ-056 | MUST | `RELEASE` 前重新确认 `LOCKED`；`PRELOAD → ARMED` 不要求持续 `LOCKED`，但预载未完成而 `LOCKED` 丢失超过中止窗口时退回 `READY` 并受控卸载。 | 统一架构 §6.2 |
| REQ-057 | MUST | 标定态限制在 `READY` 及以下：`CALIBRATING`/`CALIB_MODE` 期间禁止 `READY → AIM_ALLOWED`，且只能从 `READY` 发起标定。 | 统一架构 §6.3 |

---

## 9. 安全互锁

| 编号 | 类型 | 需求 | 来源 |
|---|---|---|---|
| REQ-058 | MUST | Interlock 1：`MECH_RECOVERED` 为 TRUE 时才允许进入 `PRELOAD`。 | §11 Interlock 1 |
| REQ-059 | MUST | Interlock 2：`MAG_INDEX_OK` 为 TRUE 时才允许执行 Mode B 动作。 | §11 Interlock 2 |
| REQ-060 | MUST | Interlock 3：`FIRE_INHIBIT` 为 TRUE 时 `RELEASE` 永久禁止。 | §11 Interlock 3 |
| REQ-061 | MUST | Interlock 4：`FAULT` 后必须重新 `HOME`。 | §11 Interlock 4 |
| REQ-062 | MUST | 四条互锁必须有硬件实现，软件只作第一道闸与诊断；释放能量路径由物理与门串在供电回路中。 | §10.4，统一架构 §6.5、§6.6 |
| REQ-063 | MUST | 释放门控条件同时满足：`FIRE_INHIBIT` 未断言、`EXTERNAL_ALLOW` 有效、`MECH_RECOVERED`、Mode B 载荷对齐、`ARMED` 锁存、主使能有效；任一不满足则释放回路物理断开。 | 统一架构 §6.5 H1 |
| REQ-064 | MUST | 机构未复位时预载执行器无法被驱动，通过常闭触点实现。 | 统一架构 §6.5 H2 |
| REQ-065 | MUST | 故障与急停状态锁存，复位条件接 `PAN_HOME`、`TILT_HOME`、`MAG_HOME` 三处零位开关的与。 | 统一架构 §6.4、§6.5 H4 |
| REQ-066 | MUST | `FAULT` 锁存且不自动恢复，唯一清除路径为 `SAFE → HOME → READY`，不存在 `FAULT → READY` 这条边。 | 统一架构 §6.4（裁决） |
| REQ-067 | MUST | 释放命令的驱动时间由硬件单稳态钳位，即使 MCU 卡在高电平也只产生固定短脉冲，不会持续通电。 | 统一架构 §6.6 |
| REQ-068 | MUST | `FIRE_INHIBIT` 与 `EXTERNAL_ALLOW` 的失效方向指向安全，断线、掉电、接插件松脱均落到禁止侧。 | 统一架构 §6.7 |
| REQ-069 | MUST | 机械限位用物理止挡，主电源急停用常闭蘑菇头直接串执行器供电，不经过 MCU。 | 统一架构 §6.5 H5、H6 |

---

## 10. 机械核心

| 编号 | 类型 | 需求 | 来源 |
|---|---|---|---|
| REQ-070 | MUST | Stage 1 接收低速位移、储存弹性能，达到结构临界状态时快速 snap-through。 | §5.1 |
| REQ-071 | MUST | Stage 1 不得直接接触软载荷。 | §5.1 |
| REQ-072 | MUST | Stage 2 接收 Stage 1 的机械位移，提供第二个非线性转变，改变输出时间历程并驱动膜片接口。 | §5.2 |
| REQ-073 | MUST NOT | 不得预设两级必然优于一级；Stage 2 的价值由实验判定。 | §5.2 |
| REQ-074 | MUST | 保留三个原型对照：A 普通慢推膜片，B 单级 snap，C 双级 snap。 | §5.3 |
| REQ-075 | MUST | 若 C 相对 B 更复杂、更不稳定且脉冲无明显改善，则淘汰双级方案。 | §5.3 |
| REQ-076 | MAY | 可保留 fixed boundary、released/sliding boundary、不同预载，定位为研究变量。 | §5.4 |
| REQ-077 | MUST NOT | 不得把边界调整模块当作默认专利新颖性。 | §5.4、§25.1 |

---

## 11. 柔性膜片

| 编号 | 类型 | 需求 | 来源 |
|---|---|---|---|
| REQ-078 | MUST | 膜片把快速机械位移转换为短时空气体积位移。 | §6.1 |
| REQ-079 | MUST NOT | 膜片不得设计为高压储气装置。 | §6.1 |
| REQ-080 | SHOULD | 材料候选为薄硅胶膜、TPU 薄膜、PET/Mylar 薄膜。 | §6.2 |
| REQ-081 | MUST | 第一轮至少比较一种弹性体膜与一种聚酯薄膜。 | §6.2 |
| REQ-082 | MUST NOT | 没有实验数据时不得指定唯一膜片材料。 | §6.2 |
| REQ-083 | MUST | 膜片采用可拆压环安装，不得永久胶粘。 | §6.3 |

---

## 12. 失稳元件材料

| 编号 | 类型 | 需求 | 来源 |
|---|---|---|---|
| REQ-084 | SHOULD | 高循环失稳核心不宜完全交给普通 FDM 柔性梁。 | §7.1 |
| REQ-085 | MUST | 打印件承担框架、支撑、限位、边界切换、模块定位。 | §7.1 |
| REQ-086 | MUST | snap-through 主变形由独立弹性元件承担。 | §7.1 |
| REQ-087 | SHOULD | 弹性元件候选为 301/304 弹簧不锈钢薄片、PET 弹性片、磷青铜薄片。 | §7.2 |
| REQ-088 | MUST | 原型顺序为先 PET 做几何验证，再用弹簧钢做寿命与重复性版。 | §7.2、§31 |

---

## 13. 软载荷

| 编号 | 类型 | 需求 | 来源 |
|---|---|---|---|
| REQ-089 | MUST | 主载荷为 EVA 或 EPP 超轻软质圆片。 | §8.1 |
| REQ-090 | MUST NOT | 不得使用球状载荷作为主方案。 | §8.1 |
| REQ-091 | MUST | 圆片应能平铺于旋转盘内独立约束、不自由滚动，且供给通道短、弹仓厚度低。 | §8.2 |
| REQ-092 | MAY | 备用载荷允许毛毡片、轻纸片、纸浆软片；早期验证可优先纸片或毛毡。 | §8.3 |
| REQ-093 | MUST NOT | 机械接口不得设计成可不加修改装入 BB、钢珠、玻璃珠、陶瓷珠、金属柱、飞镖、尖头件。 | §8.4 |

---

## 14. 供给系统

| 编号 | 类型 | 需求 | 来源 |
|---|---|---|---|
| REQ-094 | MUST | 供给采用 6–8 位旋转盘。 | §9.1 |
| REQ-095 | MUST NOT | 不得把旋转弹仓或供给盘当作创新点。 | §9.1 |
| REQ-096 | MUST | 供给工作序列为 READY → 一次低能量动作 → RECOVER → 确认机械核心复位 → INDEX → 转动一个固定索引 → 检测 INDEX_OK → READY。 | §9.2 |
| REQ-097 | SHOULD | 选用旋转盘的理由是软圆片在狭长通道中易翘曲、摩擦、叠片、卡住；每个载荷有独立 pocket。 | §9.3 |
| REQ-098 | MUST | "自动换弹"只表示切换下一载荷位置；空盘由人工整体更换，不实现自动拆装供给盘。 | §9.4 |
| REQ-099 | MUST | 供给盘接口满足：可拔出、唯一方向防呆、零位标记、机械止挡、MCU 可知零位、手动装回后可重新 HOME。 | §9.5 |

> 注（REQ-094 的几何补充）：按 `03_CAD/MST-01E` 的几何自检（非实测），6 位与 8 位供给盘都超出 §1.2 的横向尺寸目标，位数选择需与尺寸目标一并裁决，见 `DESIGN_DECISION_LOG.md` D-15 与 `RISK_REGISTER.md` RSK-16。

---

## 15. 炮头模式

| 编号 | 类型 | 需求 | 来源 |
|---|---|---|---|
| REQ-100 | MUST | Mode A 为纯空气模式，是项目第一工作版本，用于机械调试、膜片测试、压力波形、寿命测试、对照实验。 | §12 |
| REQ-101 | MUST | Mode B 加入超轻软圆片与旋转供给盘，用于验证供给、系统集成与动作一致性。 | §12 |
| REQ-102 | MUST NOT | Mode B 不得作为研究输出强度的版本。 | §12 |

---

## 16. 原型序列与不可跳级

| 编号 | 类型 | 需求 | 来源 |
|---|---|---|---|
| REQ-103 | MUST | MST-01A 为普通膜片基线，无 snap-through，低速执行器直接推动膜片。 | §13 |
| REQ-104 | MUST | MST-01B 为单级 snap，一个失稳单元。 | §13 |
| REQ-105 | MUST | MST-01C 为双级串联 snap，两个失稳单元。 | §13 |
| REQ-106 | MUST | MST-01D 为可切换边界研究版，含 locked/released support 或可逆边界改变、多种预载状态。 | §13 |
| REQ-107 | MUST | MST-01E 为自动供给完整版，含 6–8 位供给盘、索引、Mode B。 | §13 |
| REQ-108 | MUST | 原型顺序固定为 A → B → C → D → E，每级达到通过标准才进入下一级。 | §14 |
| REQ-109 | MUST NOT | 不得跳过 A/B/C 直接做 E，也不得删除 A/B/C 对照实验。 | §14、§34 |
| REQ-110 | MUST | D 版定位为科研变量验证，不与专利点划等号。 | §13 |

---

## 17. 实验变量与输出变量

| 编号 | 类型 | 需求 | 来源 |
|---|---|---|---|
| REQ-111 | MUST | 记录输入变量：mechanism version、boundary state、preload state、membrane material、membrane mounting、stage combination、cycle count。 | §15.1 |
| REQ-112 | MUST | 测量输出变量：force-displacement curve、Stage 1 event time、Stage 2 event time、membrane displacement-time、low-range pressure-time、recovery time、repeatability、indexing success、fatigue drift。 | §15.2 |
| REQ-113 | MUST NOT | 不得建立"最大杀伤""最大穿透""最大危险射程""最重弹丸"这类指标。 | §15.3 |

---

## 18. 第一阶段实验流程

| 编号 | 类型 | 需求 | 来源 |
|---|---|---|---|
| REQ-114 | MUST | 完成 Test A1 普通膜片，保存 A1_force.csv、A1_displacement.csv、A1_pressure.csv、A1_video.*、A1_notes.md。 | §16 |
| REQ-115 | MUST | Test B1 相对 A1 判断：膜片响应是否明显更快、是否可重复、是否产生过大振铃。 | §16 |
| REQ-116 | MUST | Test C1 判断：两个事件是否可分辨、顺序是否固定、是否偶发同时 snap、是否比 B 更有价值。 | §16 |
| REQ-117 | MUST | Test D1 至少取 BOUNDARY_0 与 BOUNDARY_1 两个状态，比较 force-displacement、stage order、inter-stage delay、membrane response。 | §16 |

---

## 19. 寿命与供给盘验收

| 编号 | 类型 | 需求 | 来源 |
|---|---|---|---|
| REQ-118 | MUST | 循环寿命按 100、500、1000 次阶梯测试。 | §17 |
| REQ-119 | MUST | 每个寿命阶段检查 snap threshold 漂移、裂纹、塑性变形、膜片松弛、螺丝松动、传感误判、恢复失败。 | §17 |
| REQ-120 | MUST | 若 100 次已明显漂移，不得进入集成版。 | §17 |
| REQ-121 | MUST | 供给模块先脱离炮头单独运行。 | §18 |
| REQ-122 | MUST | Test M1 连续 50 次索引，记录 index_command、index_detected、jam、double_feed、misalignment、manual_reset。 | §18 |
| REQ-123 | MUST | 第一版 50 次索引中人工复位不超过 1 次。 | §18 |

---

## 20. 数据格式

| 编号 | 类型 | 需求 | 来源 |
|---|---|---|---|
| REQ-124 | MUST | 每次动作保存字段：timestamp、experiment_id、prototype_version、mechanism_version、mode、boundary_state、preload_state、membrane_id、payload_id、cycle_count、stage1_event、stage2_event、mechanism_recovered、magazine_position、magazine_index_ok、fault_code、operator_note。 | §19 |
| REQ-125 | MUST | `fault_code` 使用结构化故障码枚举，不用自由文本事件代替。 | 统一架构 §6.4、§6.9 第 10 条 |

---

## 21. 目录结构

| 编号 | 类型 | 需求 | 来源 |
|---|---|---|---|
| REQ-126 | MUST | 仓库按 §20 组织：00_MASTER_SPEC、01_PRIOR_ART、02_REQUIREMENTS、03_CAD、04_SIMULATION、05_FIRMWARE、06_BOM、07_EXPERIMENTS、08_DATA、09_PLOTS、10_FAILURE_ANALYSIS、11_PUBLICATION_NOTES。 | §20 |

---

## 22. CAD 原则

| 编号 | 类型 | 需求 | 来源 |
|---|---|---|---|
| REQ-127 | MUST | CAD 至少拆分为 FRAME、STAGE_1、STAGE_2、BOUNDARY_MODULE、DIAPHRAGM_MODULE、PAYLOAD_MODULE、MAGAZINE_MODULE。 | §22.1 |
| REQ-128 | MUST | 每个核心模块可单独拆、单独测、能被照片或高速视频看到、可更换弹性件、不破坏外壳就能换膜片。 | §22.2 |
| REQ-129 | MUST NOT | 第一版不得追求最漂亮、最薄、最少螺丝、全部一体打印；优先满足看得见、拆得开、测得到。 | §22.3 |

---

## 23. 仿真要求

| 编号 | 类型 | 需求 | 来源 |
|---|---|---|---|
| REQ-130 | MUST | 准静态仿真至少给出 force-displacement、stable branches、snap point、Stage 1/Stage 2 顺序、boundary sensitivity。 | §23.1 |
| REQ-131 | MUST | 瞬态仿真至少研究 snap 后速度、stage interval、membrane motion、structural ringing。 | §23.2 |
| REQ-132 | SHOULD | 参数扫描优先 boundary stiffness、preload、stage mismatch、membrane stiffness、mechanical damping；不要盲目扫全部几何尺寸。 | §23.3 |

---

## 24. 研究问题表述

| 编号 | 类型 | 需求 | 来源 |
|---|---|---|---|
| REQ-133 | MUST | 研究问题表述为：紧凑串联弹性失稳机构与膜片负载耦合后，边界状态、级间非线性与膜片柔度如何共同影响瞬态机械脉冲的形成。 | §24 |
| REQ-134 | MUST NOT | 不得把项目表述为"我们发明了一种新的炮"。 | §24 |
| REQ-135 | MUST | 核心研究假设为：串联非线性弹性机构直接耦合柔性膜片时，单元数量、边界状态、预载与膜片柔度能否产生稳定、可重复、可区分的瞬态脉冲时间历程，相对普通直接驱动或单级 snap 是否有工程价值。 | §35 |
| REQ-136 | MUST | 研究核心冻结为多级非线性机械核心与柔性膜片负载之间的瞬态耦合、可重复脉冲整形与小型化。 | §29、§38 |

---

## 25. 新颖性表述纪律

| 编号 | 类型 | 需求 | 来源 |
|---|---|---|---|
| REQ-137 | MUST NOT | 不得把以下声称为新颖点：bistable/snap-through、sequential snap-through、serial snap-through、programmable multistage snap、locked/released boundary 调 snap、bistable membrane valve、snap-action diaphragm air pulse、snap action + soft projectile air launch、compliant projectile launcher、automatic rotary magazine、motorized soft-dart rotary magazine、微型/MEMS bistable mechanism。 | §25.1、§38 |
| REQ-138 | MUST | 可以表述为：候选研究贡献、本离线资料未包含完全同构单一来源、需要后续专利检索确认、系统级组合待验证。 | §28 |
| REQ-139 | MUST NOT | 不得表述为：全球首创、从未有人做过、具有确定专利新颖性、可直接申请专利且一定通过。 | §28 |
| REQ-140 | MUST | 专利态度为高 prior-art 密度，只有具体结构与系统组合完成后才进入正式 claim-level 新颖性检索。 | §38 |
| REQ-141 | MUST | 可主张的研究方向限于：低成本、微型、直接机械耦合的多级失稳—膜片负载系统在不同边界状态下能否产生可重复、可选择的瞬态脉冲时间历程。 | §25.2 |

---

## 26. 失败条件与停止条件

| 编号 | 类型 | 需求 | 来源 |
|---|---|---|---|
| REQ-142 | MUST | STOP-01：单级 snap 相对普通膜片没有可测优势时，停止双级研究。 | §30 |
| REQ-143 | MUST | STOP-02：双级比单级明显更差（更不稳定、响应无区别、寿命下降严重）时回退单级。 | §30 |
| REQ-144 | MUST | STOP-03：boundary switching 没有稳定可复现的输出差异时，D 版不进入论文主线。 | §30 |
| REQ-145 | MUST | STOP-04：供给盘 50 次测试频繁卡料时先修供给，不与炮头集成。触发门槛取 REQ-123 的量化值。 | §30 |
| REQ-146 | MUST | STOP-05：机械本体预计成本超过 ¥50 时简化零件。 | §30 |
| REQ-147 | SHOULD | STOP 响应区分记录型与运行期故障：STOP-01/02/03 记录并降级，STOP-04 进软故障并保留升级条件，STOP-05 做成 BOM 校验门槛。 | 统一架构 §6.8 |

---

## 27. Agent 不得追问的默认决策

| 编号 | 类型 | 需求 | 来源 |
|---|---|---|---|
| REQ-148 | MUST | 材料无指定时先做 PET 原型，再做弹簧钢验证版。 | §31 |
| REQ-149 | MUST | 膜片无指定时至少并行测试弹性体膜与 PET 膜。 | §31 |
| REQ-150 | MUST | 低载荷、小角度下优先铜套或打印导向，确有必要才加轴承。 | §31 |
| REQ-151 | MUST | 8 位使整体明显变大时先做 6 位，可靠后再做 8 位。 | §31 |
| REQ-152 | MUST | 结构过大时先保证重复性，再缩小。 | §31 |
| REQ-153 | MUST | 方案漂亮但不好测时选好测的。 | §31 |
| REQ-154 | MUST | 未规定参数按 安全 > 可重复性 > 可靠性 > 小型化 > 成本 > 输出强度 决策。 | §39 |

> 注（REQ-151 的几何补充）：6 位与 8 位供给盘都超出 §1.2（`03_CAD/MST-01E` 几何自检，非实测），位数选择需与尺寸目标一并裁决，见 `DESIGN_DECISION_LOG.md` D-15 与 `RISK_REGISTER.md` RSK-16。

---

## 28. 执行机构与视觉边界（裁决派生）

| 编号 | 类型 | 需求 | 来源 |
|---|---|---|---|
| REQ-155 | MUST | 第二期云台使用微型舵机位置指令；删除 motor_driver、encoder、axis 与双环 PID，保留 angle_utils 与 pid 的限幅部分。 | 统一架构 §7（裁决） |
| REQ-156 | SHOULD | 优先选带总线反馈的舵机，使 PAN_HOME/TILT_HOME 退化为上电校验；云台舵机不计入 ¥50，预算不构成约束。 | 统一架构 §6.10 |
| REQ-157 | MUST | 上电归零：释放链固定在禁止侧、预载使能断开；参考开关触发后记物理基准，tilt 以限幅速度驱向参考方向；3 秒未触发或触发后丢失即归零失败进 FAULT，绝不进 READY。 | 统一架构 §6.10 |
| REQ-158 | SHOULD | 失速检测用电流、母线电压跌落、到位超时等判据；检测到失速先停该轴、回退、重试一次，仍失败则标记该轴退化并禁止进入 AIM_ALLOWED，不直接进 FAULT。 | 统一架构 §6.10 |
| REQ-159 | MUST | 视觉保留为目标来源，只做目标在画面中的位置、指向解算、标定。 | 统一架构 §2.1（裁决） |
| REQ-160 | MUST NOT | 视觉不得做目标识别与分类、生物特征、任何与蚊虫相关的检测。 | 统一架构 §2.1、§0.1 |
| REQ-161 | MUST | 单片 MCU 方案下，PRELOAD/RELEASE 时序与视觉处理隔离，放在定时器中断或独立任务，不排在视觉处理之后。 | 统一架构 §3.1、§9 |

---

## 29. 必须交付的文件

| 编号 | 类型 | 需求 | 来源 |
|---|---|---|---|
| REQ-162 | MUST | 最终至少交付 REQUIREMENTS.md、SYSTEM_ARCHITECTURE.md、INTERFACES.md、DESIGN_DECISION_LOG.md、BOM.csv、RISK_REGISTER.md、TEST_PLAN.md、FAILURE_MODES.md、STATE_MACHINE.md、DATA_SCHEMA.md。 | §33 |
| REQ-163 | MUST | 交付 MST-01A 到 MST-01E 的 CAD。 | §33 |
| REQ-164 | SHOULD | 设计决策日志每条包含 decision、reason、alternative、evidence、validation、failure condition。 | §32 TASK-05 |

---

# 附录 A 冲突与裁决

规格书内部以及与已冻结决策之间需要对齐的地方，逐条列出裁决。

| 编号 | 位置 | 冲突内容 | 裁决 | 依据 |
|---|---|---|---|---|
| C-01 | §0.1、§2.1、§34 与 统一架构 §2.1 | 规格书说不要求计算机视觉、不要重做视觉系统；产品包含视觉瞄准与指向解算。 | 视觉留作目标来源。做目标在画面中的位置、指向解算、标定；不做目标识别分类、生物特征、蚊虫检测。 | 统一架构 §2.1；§0.1 已说明"打蚊子"只是体量与形态类比 |
| C-02 | §4、§10 与 统一架构 §7 | 规格书按两轴指向机构加编码器/电机电流设计；统一架构把执行机构改为微型舵机并删除电机闭环。 | 第二期云台改微型舵机位置指令；删除电机闭环层；保留角度环绕与 PID 限幅；电流只用于失速检测。 | 统一架构 §7、§6.10 |
| C-03 | §10.1 与 统一架构 §6.1 | §10.1 把发射链画成单条扁平序列；指向质量与发射周期实际并发。 | 采用双区域状态机（区域 A 发射周期，区域 B 指向质量），跨区用守卫矩阵；不压平为单一枚举。 | 统一架构 §6.1 |
| C-04 | §10.1 与 §11 Interlock 4 | §10.1 给 ANY → FAULT → SAFE，没回到 HOME；Interlock 4 要求 FAULT 后必须重新 HOME。 | FAULT 锁存不自动恢复，唯一清除路径 SAFE → HOME → READY，不存在 FAULT → READY。 | 统一架构 §6.4 |
| C-05 | §10.2 与 §11 | §10.2 把 EXTERNAL_ALLOW 列为逻辑输入；§11 四条互锁没有把它纳入释放门。 | EXTERNAL_ALLOW 参与释放硬件与门 H1，与 FIRE_INHIBIT 构成两条独立许可链，任一否决即断开。 | 统一架构 §6.6、§6.7 |
| C-06 | §10.2 与 统一架构 §7 | §10.2 允许编码器、电机电流辅助判定作为逻辑输入实现；统一架构删除编码器与电机闭环。 | 云台去编码器，改用参考开关与总线舵机位置反馈；电机电流仅作 I2C 母线电流监控的失速判据。 | 统一架构 §7、§6.10 |
| C-07 | §18 与 §30 STOP-04 | §18 给出 50 次人工复位不超过 1 次的量化门槛；STOP-04 只说"频繁卡料"，没有量化。 | 以 50 次人工复位超过 1 次作为 STOP-04 的触发门槛。 | 两处取更严的量化值；统一架构 §6.8 |
| C-08 | §20 与 §33 | §20 用小写 requirements.md、interfaces.md、safety-boundary.md；§33 用大写 REQUIREMENTS.md，且交付集不同。 | 交付物以 §33 清单为准并采用大写文件名；目录沿用 §20 结构，文件按 §33 补全。 | §33 是交付清单，§20 是目录树 |
| C-09 | §4 与 统一架构 §2.1 | §4 架构图把"外部上层控制/目标坐标"画在项目外并注明来源不属于本项目范围；统一架构判定视觉属于产品内部。 | 该格由本项目的视觉模块提供，架构图的外/内边界就此失效。 | 统一架构 §2.1 |
| C-10 | §10.3 与 统一架构 §4.3 | §10.3 列 DEBUG_TX 专用输出；统一架构引脚表未分配专用脚，改用 UART0/USB CDC。 | DEBUG_TX 映射到 UART0 或 USB CDC，作为预留。 | 统一架构 §4.3 |
| C-11 | §10.2 与 统一架构 §6.6 | §10.2 只有 MAG_INDEX_OK，未单列载荷对齐信号；统一架构给模式 B 增加 POCKET_ALIGNED/对齐开关。 | 对齐检测并入 MAG_INDEX_OK 通道，模式 B 时参与 H1；模式 A 由继电器旁路为真。 | 统一架构 §6.5 H3、§6.6 |
| C-12 | §5、§13 与 统一架构 §6.11 | 规格书未规定 ARMED 态能否安全卸载；统一架构指出这是决定状态机可用性的机械能力。 | A/B/C 阶段必须验证 ARMED 安全卸载能力；若不支持，ARMED 中止只能停 FAULT 并保持硬件断开。 | 统一架构 §6.11 |
| C-13 | §1.1 与 §21 | §1.1 把低密度软载荷计入 ¥50；软载荷属耗材，后续更换不宜反复计入 BOM 目标。 | 首次配备的软载荷计入，后续消耗不计入 BOM 目标。此条归类待确认。 | 工程解释，需 DESIGN_DECISION_LOG 记录 |
| C-14 | §25.2 与 §30 STOP-03 | §25.2 说低成本多级失稳—膜片系统的边界效应可继续验证；STOP-03 说边界差异不稳定时 D 版不进论文主线。 | 表面冲突，判定不冲突：边界研究保留为条件分支，只有出现稳定差异才进入论文主线。 | §25.2、§30 |
| C-15 | §10.2 与 统一架构 §6.10 | §10.2 把"电机电流辅助判定"列为逻辑输入实现；统一架构用舵机后该判据不再适用，但失速检测仍需要电流。 | 编码器判定废止；电流判定保留但用途改为舵机失速检测，不参与零位参考。 | 统一架构 §6.10 |

---

# 附录 B 需求覆盖自检

规格书章节到本文档的落点。判定为"无需求条目"的章节给出原因。

| 章节 | 落点 | 备注 |
|---|---|---|
| §0.1 | REQ-001、REQ-002、REQ-159、REQ-160 | 定义与禁止项 |
| §0.2 | REQ-003 | 工程称谓 |
| §0.3 | REQ-007 到 REQ-018 | 安全边界与优先级 |
| §1.1 | REQ-019 到 REQ-022 | 成本边界 |
| §1.2 | REQ-026 到 REQ-028 | 尺寸 envelope |
| §1.3 | REQ-029、REQ-030 | 控制原则 |
| §2.1 | REQ-002 | 删除蚊虫相关内容 |
| §2.2 | REQ-074、REQ-077、REQ-137 | 新颖性修正 |
| §3 | REQ-001、REQ-070 到 REQ-075 | 工程基线 |
| §4 | REQ-001、REQ-159 | 系统架构与视觉归属裁决 |
| §5.1 | REQ-070、REQ-071 | Stage 1 |
| §5.2 | REQ-072、REQ-073 | Stage 2 |
| §5.3 | REQ-074、REQ-075 | 单级对照 |
| §5.4 | REQ-076、REQ-077 | 边界调整模块 |
| §6.1 | REQ-078、REQ-079 | 膜片功能 |
| §6.2 | REQ-080 到 REQ-082 | 膜片材料 |
| §6.3 | REQ-083 | 膜片安装 |
| §7.1 | REQ-084 到 REQ-086 | 失稳元件结构 |
| §7.2 | REQ-087、REQ-088 | 弹性元件材料 |
| §8.1 | REQ-089、REQ-090 | 主载荷 |
| §8.2 | REQ-091 | 圆片工程原因 |
| §8.3 | REQ-092 | 备用载荷 |
| §8.4 | REQ-093 | 禁止硬载荷兼容 |
| §9.1 | REQ-094、REQ-095 | 旋转供给盘 |
| §9.2 | REQ-096 | 工作逻辑 |
| §9.3 | REQ-097 | 旋转盘理由 |
| §9.4 | REQ-098 | 自动换弹含义 |
| §9.5 | REQ-099 | 供给盘接口 |
| §10.1 | REQ-052 到 REQ-054 | 状态机 |
| §10.2 | REQ-035 到 REQ-043 | 逻辑输入 |
| §10.3 | REQ-044 到 REQ-051 | 输出 |
| §10.4 | REQ-031 到 REQ-034、REQ-062 | MCU 禁止项 |
| §11 | REQ-058 到 REQ-061 | 四条互锁 |
| §12 | REQ-100 到 REQ-102 | 模式 A/B |
| §13 | REQ-103 到 REQ-107、REQ-110 | 原型序列 |
| §14 | REQ-108、REQ-109 | 不可跳级 |
| §15.1 | REQ-111 | 输入变量 |
| §15.2 | REQ-112 | 输出变量 |
| §15.3 | REQ-016、REQ-113 | 排除的优化目标 |
| §16 | REQ-114 到 REQ-117 | 实验流程 |
| §17 | REQ-118 到 REQ-120 | 循环寿命 |
| §18 | REQ-121 到 REQ-123 | 供给盘验收 |
| §19 | REQ-124、REQ-125 | 数据格式 |
| §20 | REQ-126 | 目录结构 |
| §21 | REQ-023 到 REQ-025 | BOM 目标与削减顺序 |
| §22.1 | REQ-127 | CAD 模块化 |
| §22.2 | REQ-128 | 可测试性 |
| §22.3 | REQ-129 | 避免过早一体化 |
| §23.1 | REQ-130 | 准静态仿真 |
| §23.2 | REQ-131 | 瞬态仿真 |
| §23.3 | REQ-132 | 参数扫描 |
| §24 | REQ-133、REQ-134 | 研究问题表述 |
| §25.1 | REQ-137 | 不能主张的新颖点 |
| §25.2 | REQ-141 | 可研究范围 |
| §26 | 无需求条目 | 最接近 prior art 的证据汇编，约束经 §25、§28 表达 |
| §27 | 无需求条目 | prior-art 矩阵属证据，不产生独立需求 |
| §28 | REQ-138、REQ-139 | 可以说/不可以说 |
| §29 | REQ-136 | 继续研究的理由 |
| §30 | REQ-142 到 REQ-147 | STOP-01 到 STOP-05 |
| §31 | REQ-148 到 REQ-153 | 默认决策 |
| §32 | REQ-164 | TASK-01 由本文件承担；TASK-02 到 TASK-07 属流程，落在 CAD、仿真、实验、决策日志交付物，不单列需求 |
| §33 | REQ-162、REQ-163 | 交付文件 |
| §34 | REQ-004 到 REQ-006、REQ-109 | 不要做的事 |
| §35 | REQ-135 | 最终研究假设 |
| §36 | 无需求条目 | 交接 12 条摘要，内容已分散到各主题 |
| §37 | 无需求条目 | v2.0 自查清单，不含新需求 |
| §38 | REQ-002、REQ-136、REQ-137、REQ-140 | 最终冻结结论 |
| §39 | REQ-007、REQ-154 | 启动指令与冻结约束 |
| §40 | 无需求条目 | 文档优先级声明，v2.0 为准 |

覆盖结论：§0 到 §25 除 §2.2、§29 等以派生条目落地外全部有需求落点；§26、§27 判定为证据章节无独立需求；§32 除 TASK-01 外判定为流程任务；§36、§37、§40 判定为摘要或声明，无新需求。§29、§35 以研究框架需求落地。

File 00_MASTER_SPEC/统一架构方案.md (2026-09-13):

# 统一架构方案

MST-01 微型定向低能量脉冲平台的系统架构。这份文档取代此前把"视觉瞄准"与"脉冲炮头"分开描述的做法：
它们是同一件产品，分两期实现，先易后难。

版本 0.1.0。状态机与安全互锁部分由独立评审给出，见第 6 节。

---

## 1. 项目定义与分期

产品是一台 MCU 控制、火柴盒级、低能量、可模块化供给超轻软载荷的二维指向式快速机械脉冲执行平台。
整机由三块组成：**找目标的视觉**、**指向目标的云台**、**产生脉冲的机械核心**。

分两期做，原因只是难度递进，不是两个东西：

| 期 | 内容 | 状态 |
|---|---|---|
| 第一期 | 视觉定位、角度解算、标定、指向闭环、遥测与工具链 | 已完成（`00_MASTER_SPEC/`、`02_REQUIREMENTS/`、`05_FIRMWARE/`、`07_EXPERIMENTS/tools/`） |
| 第二期 | 两级串联失稳脉冲核心、柔性膜片、旋转供给盘、完整发射周期 | 待做 |

第一期交付的东西在第二期全部保留。第一期里的 `Transmitter` 抽象层就是第二期脉冲核心的挂载点。

---

## 2. 与 MST-01 规格书的关系

规格书是 `MST-01_Offline_Agent_Master_Spec_v2.0`，它是本产品的机械与执行规格，本文件是系统架构。

### 2.1 §34「不要研究目标检测」的处理

规格书 §34 禁止"研究目标检测、重做视觉系统"。那一段的原意是防止把项目重新发散成灭蚊器（§0.1 已说明
"打蚊子"只是尺寸与形态的类比）。本项目本来就不做蚊虫识别、翼频检测、生物特征分类。

视觉留作产品的目标来源，理由：规格书 §4 的系统架构图里有一格是"外部上层控制/目标坐标"，并注明
"具体来源不属于本项目范围"。那一格就是本项目的视觉部分，规格书把它画成外部是因为它当时只写炮头。
把两者合起来看，视觉属于产品内部。

为避免以后又把它当成违规，这里定下边界：

- 做：目标在画面中的位置、指向解算、标定。
- 不做：目标识别与分类、生物特征、任何与蚊虫相关的检测。

---

## 3. 系统架构

```
                    ┌──────────────────────────────────────────────┐
                    │              ESP32-S3（单片）                 │
                    │                                              │
    OV2640/5640 ───►│  vision         solver          gimbal       │
   （14 根并口）     │  取帧/分割   →   角度解算/       → 舵机 PWM     │
                    │  亚像素质心     滤波/提前量        pan + tilt   │
                    │                   │                           │
                    │                   ▼                           │
                    │              cycle 状态机                     │
                    │         （第一期瞄准态 + 第二期发射周期）        │
                    │                   │                           │
   MCP23017 ◄──────►│ I2C0           直接 GPIO                      │
   慢速离散 I/O       │                   │                           │
                    └───────────────────┼───────────────────────────┘
                                        │
        ┌───────────────────────────────┼───────────────────────────┐
        ▼                               ▼                           ▼
   ┌─────────┐                  ┌──────────────┐            ┌─────────────┐
   │ 舵机云台 │                  │ BOUNDARY     │            │ 旋转供给盘   │
   │ pan/tilt│                  │ PRELOAD      │            │ 6–8 位      │
   └─────────┘                  │ RELEASE      │            └─────────────┘
                                └──────┬───────┘
                                       ▼
                        ┌──────────────────────────────┐
                        │ 两级串联失稳 + 柔性膜片       │
                        │ Stage 1 ↓ Stage 2 ↓ 膜片     │
                        └──────────────┬───────────────┘
                                       ▼
                          Mode A 纯空气 / Mode B 软载荷
```

### 3.1 单片 MCU 的取舍

第一期的方案用双 MCU（视觉板 + 炮头板），前提是当时引脚不够。执行机构从 12V 减速电机改成微型舵机后，
电机闭环层整体删除，释放 11 个 GPIO（pan 电机 1/2/14、tilt 电机 21/47/48、STBY 38、编码器 39/40/41/42），
引脚预算翻了过来，单片即可覆盖全部信号。

选单片而不是双片：

- 火柴盒级产品，多一块板多一份体积、功耗与成本。
- 没有跨 MCU 协议，就没有协议失配、版本不一致、通信超时这三类故障。
- RELEASE 到膜片的时序在片内，不受总线延迟影响。

代价：视觉循环与发射时序共享一个 CPU。用非阻塞状态机 + 固定节拍控制环隔离，第二期的 PRELOAD/RELEASE
动作放在定时器中断或独立任务里，不排在视觉处理后面。这一条在第二期实现时必须验证，见第 9 节。

### 3.2 机械基线的模型预警

§3 的两级串联基线与 D-01 的冻结，前提是双级相对单级有实际价值。`04_SIMULATION/` 的纯软件模型（非实测）
在名义参数下给出不同倾向：C 相对 B 的膜片峰值速度只有约 18% 的增益，输入功接近翻倍，级序在刚度失配下会翻转。
模型没有干净命中 STOP-02，也不足以单方面推翻基线。决策当前状态、风险条目与两级实验的先验预测分别记在
`DESIGN_DECISION_LOG.md` 的 D-14、`RISK_REGISTER.md` 的 RSK-10、`TEST_PLAN.md` 的 B1/C1 通过标准处。
最终结论由 §16 的 A1/B1/C1 实验给出。

---

## 4. 引脚与资源重新核算

### 4.1 已占用

| 用途 | GPIO | 备注 |
|---|---|---|
| 摄像头 DVP | 4,5,6,7,8,9,10,11,12,13,15,16,17,18 | 14 根，含 SCCB、XCLK、PCLK、VSYNC、HREF、D0–D7 |
| UART0 | 43,44 | 遥测与标定外壳，或改走 USB CDC |
| LEDC timer2/ch2 | — | 摄像头 XCLK |

### 4.2 不可用

| GPIO | 原因 |
|---|---|
| 26–32 | Flash 与 PSRAM 的 SPI |
| 33–37 | N16R8 八线 OPI PSRAM 的额外数据线 |
| 22–25 | 芯片不引出 |
| 19,20 | 原生 USB D±，放弃 USB 调试后才可用 |

### 4.3 第二期信号分配

| 信号 | 方向 | 分配 | 理由 |
|---|---|---|---|
| `PAN_CMD` | 输出 | 直连 PWM，LEDC ch3 | 舵机，需要稳定抖动低的 PWM |
| `TILT_CMD` | 输出 | 直连 PWM，LEDC ch4 | 同上 |
| `RELEASE_CMD` | 输出 | 直连 GPIO | 必须最快、最确定，不经总线 |
| `STAGE1_STATE` | 输入 | 直连 GPIO，中断 | 失稳事件时间要精确捕获（§15.2 输出变量） |
| `STAGE2_STATE` | 输入 | 直连 GPIO，中断 | 同上，且要判定两级顺序 |
| `BOUNDARY_CMD` | 输出 | MCP23017 | 慢速，机械改边界 |
| `PRELOAD_CMD` | 输出 | MCP23017 | 慢速，预载 |
| `MAG_INDEX_CMD` | 输出 | MCP23017 | 慢速，索引一步 |
| `MAG_HOME` | 输入 | MCP23017 | 慢速 |
| `MAG_INDEX_OK` | 输入 | MCP23017 | 慢速，索引到位确认 |
| `MECH_RECOVERED` | 输入 | MCP23017 | 慢速，机构复位确认 |
| `PAN_HOME` | 输入 | MCP23017 | 上电归零才用到 |
| `TILT_HOME` | 输入 | MCP23017 | 同上 |
| `FIRE_INHIBIT` | 输入 | MCP23017 | 慢速安全信号 |
| `STATUS_LED` | 输出 | MCP23017 或直连 | 指示用 |

I2C0 只占 2 个脚（SDA/SCL），从 MCP23017 扩出 16 路，上面用了 10 路，余 6 路留给后续。

### 4.4 资源余量

| 外设 | 已用 | 剩余 |
|---|---|---|
| LEDC | ch2（摄像头 XCLK）、ch3/ch4（两舵机） | ch0/1/ch5–ch7、timer0/1/3 |
| PCNT | 无（编码器层已删） | 全部 4 个单元 |
| UART | UART0 | UART1、UART2 |
| I2C | I2C1 已被摄像头 SCCB 占用 | I2C0 用于 MCP23017 |
| SPI | SPI0/1 内部占用 | SPI2(FSPI)、SPI3，需要引脚 |
| ADC | 无 | 无空闲脚，需要电流/电压采样就挂 I2C ADC |

Flash 与 RAM 余量充足（第一期实测 Flash 5.9%、RAM 7.9%），真正的约束是引脚与外设，不是存储。

### 4.5 上电前必须核对的引脚风险

`TB6612_STBY_PIN` 用的 38、`TILT_AIN1_PIN`/`TILT_AIN2_PIN` 用的 47/48，在 ESP32-S3-DevKitC-1 上
可能接着板载 RGB LED。这三条随电机层一起删除，风险自动消失。第二期重新分配引脚时同样要避开
被板载外设占用的脚，方法一样：对照实物原理图逐个确认。

---

## 5. 目录重组

最终按 MST-01 §20 的结构组织，第一期已产出的内容已经就位。

```
MST-01/
├── 00_MASTER_SPEC/         规格书与本架构文档
├── 01_PRIOR_ART/           现有来源摘要、claim 矩阵、版本修正
├── 02_REQUIREMENTS/        需求、接口、安全边界
├── 03_CAD/                 MST-01A ~ E
├── 04_SIMULATION/          准静态、瞬态、参数扫描
├── 05_FIRMWARE/            状态机、I/O 映射、故障码
├── 06_BOM/                 物料
├── 07_EXPERIMENTS/         A ~ E 实验数据
├── 08_DATA/
├── 09_PLOTS/
├── 10_FAILURE_ANALYSIS/
└── 11_PUBLICATION_NOTES/
```

第一期内容落位：

| 内容 | 位置 |
|---|---|
| PlatformIO 固件工程 | `05_FIRMWARE/` |
| 算法参考实现 | `05_FIRMWARE/algo_reference/`（与固件配对） |
| 标定与评估工具链 | `07_EXPERIMENTS/tools/` |
| 方案设计 | `02_REQUIREMENTS/方案设计.md` |
| 标定与几何推导 | `02_REQUIREMENTS/标定与几何推导.md` |
| 硬件接线与选型 | `02_REQUIREMENTS/硬件接线与选型.md` |
| 引脚分配与扩展预留 | `05_FIRMWARE/io-map.md` |
| 统一架构方案 | `00_MASTER_SPEC/统一架构方案.md` |

搬迁同时修正了构建与脚本里写死的相对路径，构建与测试已重新验证。

---

## 6. 状态机与安全互锁

### 6.1 做成双区域状态图，不拉平成一个枚举

11 个发射周期状态管的是"谁在储能、谁在释放"，7 个指向状态管的是"有没有看到目标、误差是否在死区"。
两件事天然并发：`PRELOAD` 期间可以仍处于 `TRACKING`，`READY` 期间也可以处于 `SEARCHING`。

塞进一个枚举会得到 11×7 的笛卡尔空间，其中绝大多数组合非法。用扁平枚举等于用缺席表达非法组合，
漏判一处就会进入"不可能状态"。发射链是安全相关代码，人工维护合法性矩阵正是最不该出错的地方。

所以分成两个区域，各自有转移表，跨区域用一张守卫矩阵约束。

**区域 A（发射周期）**：`BOOT SAFE HOME READY AIM_ALLOWED PRELOAD ARMED RELEASE RECOVER INDEX FAULT`
**区域 B（指向质量）**：`IDLE CALIBRATING SEARCHING TRACKING LOCKED CALIB_MODE`

旧 `AimState` 的落位：

| 旧状态 | 区域 A | 区域 B |
|---|---|---|
| `IDLE` | `READY` | `IDLE` |
| `CALIBRATING` | `HOME` | `CALIBRATING` |
| `SEARCHING` | `READY` | `SEARCHING` |
| `TRACKING` | `READY` | `TRACKING` |
| `LOCKED` | `READY` 或 `AIM_ALLOWED` | `LOCKED` |
| `CALIB_MODE` | `READY` | `CALIB_MODE` |
| `FAULT` | `FAULT` | 冻结 |

跨区域守卫矩阵（区域 B 决定区域 A 能走多远）：

| 区域 B | 允许的最高区域 A 状态 |
|---|---|
| `IDLE` / `SEARCHING` / `TRACKING` | `READY` |
| `LOCKED` | 全链 |
| `CALIBRATING` / `CALIB_MODE` | `READY`（禁止进入 `PRELOAD` 及之后） |

### 6.2 `AIM_ALLOWED` 与 `LOCKED` 的关系

`LOCKED` 是进入 `AIM_ALLOWED` 的入场条件，进入之后两者并存。`LOCKED` 是持续评估的质量谓词，
`AIM_ALLOWED` 是被授予并短暂保持的许可态。

依据是规格书自己的排序：§10.1 把 `AIM_ALLOWED` 放在 `READY` 之后、`PRELOAD` 之前。这个位置只有一种
合理解释，就是"指向已经可信，允许开始储能量"。若不依赖指向质量，它和 `READY` 就没有区别。

进入之后不能一丢 `LOCKED` 就退，否则一次丢帧就要在 `PRELOAD` 门口反复启停。落地规则：

- `AIM_ALLOWED → PRELOAD` 要求此刻仍为 `LOCKED`。
- `PRELOAD → ARMED` 不要求持续 `LOCKED`，但预载未完成时 `LOCKED` 丢失超过中止窗口就退回 `READY`
  并受控卸载（前提是机构支持安全卸载）。
- `ARMED → RELEASE` 是最后一道指向门，释放前一瞬重新确认 `LOCKED`，`ARMED` 停留期间指向子机继续跟。

`RELEASE` 不可逆，所以指向与发射许可之间必须存在一个耦合点，就是 `RELEASE` 门。完全解耦会留下
"许可还在、目标已经跑了"的窗口，那正是安全最不能接受的窗口。

### 6.3 标定期间的位置

`CALIBRATING` 与 `CALIB_MODE` 都限制在 `READY` 及以下，三层保证：

1. 软件守卫：区域 B 处于标定态时禁止 `READY → AIM_ALLOWED`。
2. 从 `ARMED` 或 `PRELOAD` 请求进入标定直接拒绝，只能在 `READY` 发起，且先卸载残余储能。
3. 硬件：标定期间软件主动把 `MECH_RECOVERED_N` 与 `FIRE_INHIBIT_N` 置到禁止侧，释放通道物理断开。

`CALIBRATING` 与 `CALIB_MODE` 的区别保留：前者是"标定数据无效，系统自动停留"，后者是"操作者手动建标定"。

### 6.4 `FAULT` 统一：锁存，但唯一出口经过 `HOME`

规格书 §11 Interlock 4 要求故障后必须重新 `HOME`；现有实现是置位后永不复位。统一成一句话：
**`FAULT` 锁存，不自动恢复，唯一清除路径是 `SAFE → HOME`，`FAULT → READY` 这条边不存在。**

- 引入故障码与严重级，对应 §19 的 `fault_code`。现在用自由文本事件不算故障码。
- 软故障（自检瞬时失败、观测链路异常、索引连续失败）允许 `FAULT → SAFE → HOME → READY`，
  其中 `HOME` 必须真实完成且参考开关全中。
- 硬故障（释放门控自检失败、机械卡死、参考开关矛盾）保持锁存，软件清除无效，必须断电或人工处理。
- 清除命令只把系统送到 `SAFE`，不直接到 `READY`。
- 硬件绑死：故障锁存器的复位条件接 `PAN_HOME & TILT_HOME & MAG_HOME`，机构没真回零位就复位不了。

### 6.5 硬转移与软转移

硬转移由物理通道决定，固件即使卡死或输出错误电平也无法完成。

| 编号 | 硬约束 | 实现 |
|---|---|---|
| H1 | 释放能量路径仅在 `FIRE_INHIBIT` 未断言、`EXTERNAL_ALLOW` 有效、`MECH_RECOVERED`、模式 B 时载荷对齐、`ARMED` 锁存、主使能有效时导通 | 物理与门串在释放执行器的供电回路 |
| H2 | 机构未复位时预载执行器无法被驱动 | 预载使能串 `MECH_RECOVERED_N` 常闭触点 |
| H3 | 模式 B 未对齐时释放无法完成 | 对齐开关接入 H1 与门；模式 A 用继电器旁路，默认旁路在安全侧 |
| H4 | 故障与急停锁存，未重新归零不能复位 | SR 锁存或自保持继电器，复位接 HOME 开关 |
| H5 | 超出机械限位 | 物理止挡 |
| H6 | 主电源急停 | 常闭蘑菇头直接串执行器供电，不经 MCU |

软转移是软件判定：`LOCKED` 判定、观测新鲜度、许可授予、预载到位、索引完成与重试、冷却与超时、
看门狗、故障码分类、模式选择。软转移可以当第一道闸，但不能是唯一一道。§10.4 反对的是用软件时序
顶替机械互锁，所以 H1 到 H4 必须真实存在。

### 6.6 四条互锁的硬件与软件分工

| 互锁 | 硬件 | 软件 |
|---|---|---|
| 1：`MECH_RECOVERED` 才准 `PRELOAD` | 常闭干接点串在预载驱动使能里，机构没复位就物理断驱动 | 迁移时复查该信号，做诊断与日志 |
| 2：`MAG_INDEX_OK` 才准 Mode B | 载荷对齐开关接入 H1 与门；模式 A 用继电器旁路成真 | `INDEX` 状态负责推进与判定，连续失败升级故障并禁 Mode B |
| 3：`FIRE_INHIBIT` 时 `RELEASE` 永远禁止 | 释放供电走高边负载开关，使能由与门树给出 | 发命令前读实际电平；`PRELOAD`/`ARMED` 期间监视上升沿，置位立即安全卸载 |
| 4：`FAULT` 后必须重新 `HOME` | 故障锁存器复位接三处 HOME 开关的与 | 故障码分类 + 唯一恢复路径 |

释放门控的与门树：

```
Q1 = AND( FIRE_INHIBIT_N, EXTERNAL_ALLOW, MECH_RECOVERED_N, POCKET_ALIGNED_or_MODE_A )
Q2 = AND( Q1, ARMED_LATCH, MCU_RELEASE_CMD, MASTER_ENABLE )
Q2 -> 负载开关使能
```

一片 74HC21（双 4 输入与门）级联即可覆盖。三个关键细节：

- 每个输入按极性加下拉或上拉，开路即安全侧。`Q2` 输出加下拉，浮空等于关断。
- 释放命令不直接由 GPIO 长驱动，中间加单稳态（如 74HC123）把驱动时间上限钳死。即使 MCU 卡在
  输出高，释放也只是一个固定短脉冲，不会持续通电。
- 负载开关用低边 N-MOSFET 串在回流路径，栅极带下拉；感性负载反并续流二极管，串自恢复保险丝。

### 6.7 `FIRE_INHIBIT` 与 `EXTERNAL_ALLOW`

| 信号 | 语义 | 有效方向 | 丢失或悬空 |
|---|---|---|---|
| `FIRE_INHIBIT` | 安全否决 | 主动拉高为允许，反转后进与门 | 禁止 |
| `EXTERNAL_ALLOW` | 上级许可 | 主动拉高为许可 | 拒绝 |
| `MCU_RELEASE_CMD` | 释放请求 | 主动拉高为请求 | 无请求 |

两者失效方向都指向安全，但来源不同：`FIRE_INHIBIT` 来自安全装置（舱门开关、光幕、外接急停、机械钥匙），
是可以随时否决的红灯；`EXTERNAL_ALLOW` 来自上层，是"我有目标、我授权这一发"的绿灯。

优先级由物理与门天然保证，任一红灯亮就否决。软件里先判 `FIRE_INHIBIT` 再判 `EXTERNAL_ALLOW`，
日志分别记录，便于事后区分是安全装置拦截还是上级撤回授权。

两条线都用下拉，只有被主动驱动为高才是许可，这样断线、掉电、接插件松脱全部落到禁止侧。信号被短路到
3V3 会失去 fail-safe，缓解办法是每个否决信号用两个冗余触点做双通道交叉校验，两路不一致就按禁止处理，
并把"信号长时间无跳变"作为卡死诊断。安全完整性做到什么程度需要实验确认，先按双通道设计留位置。

### 6.8 §30 五条 STOP 条件的落地

| STOP | 性质 | 响应 |
|---|---|---|
| STOP-01 单级无可测优势 | 实验结论 | 不进 `FAULT`。落成构建期机构变体常量加研究门控标志，禁启用双级相关功能 |
| STOP-02 双级更差 | 实验结论 | 同上，构建期回退单级，记录到 `10_FAILURE_ANALYSIS` |
| STOP-03 边界无稳定差异 | 实验结论 | 不进 `FAULT`。记录并关闭边界研究分支 |
| STOP-04 供给盘频繁卡料 | 运行期条件 | 进软故障。单次在 `INDEX` 重试并记 `jam`；连续失败或检出双片/错位则禁 Mode B、保留 Mode A。若发生在储能态且机构被顶死，升级 `FAULT` 并保持硬件断开 |
| STOP-05 成本超 ¥50 | 设计期预算 | 不进运行时。做成 BOM 校验门槛，设计评审告警，按 §21 顺序砍件 |

归类：STOP-01/02/03/05 是记录加降级，STOP-04 是运行期软故障且有升级条件。把所有研究结论都变成
`FAULT` 会让系统频繁锁死，反而削弱对 `FAULT` 的信任。

### 6.9 现有代码与规格书的冲突（已定位）

| # | 位置 | 冲突 | 处理 |
|---|---|---|---|
| 1 | `main.cpp` `s_fault_latched` / `enterFault` | 置位后无清除路径，违反 §11 Interlock 4 | 加故障码与严重级，加 `faultClear()`，清除后强制走 `SAFE → HOME` |
| 2 | `main.cpp` `setup()` 结尾 | 没有 `HOME` 状态也没有归零，§10.1 的 `SAFE → HOME → READY` 完全缺失 | 补 `HOME` 状态、归零超时、失败进 `FAULT` |
| 3 | `turntable.cpp` / `main.cpp` | 归零与限位依赖编码器闭环，§10.2 要求 `PAN_HOME`/`TILT_HOME` 逻辑输入 | 舵机化后改为参考开关，见 6.10 |
| 4 | `transmitter.cpp` `setOutput` | 释放只有一路 GPIO 直写，§11 Interlock 3 要求硬件门控 | 加与门树与负载开关，见 6.6 |
| 5 | `config.h` | 缺 §10.2 全部关键输入引脚 | 按 6.10 与新 I/O 表补 |
| 6 | `aim_types.h` | 状态枚举无发射周期语义 | 按 6.1 重构为双区域 |
| 7 | `main.cpp` `aimFireTransmitter` | 只查 `!fault && LOCKED`，未查观测新鲜度与其余互锁 | 释放前重查全部互锁与 `LOCKED` 窗 |
| 8 | `main.cpp` `aimArmTransmitter` | 纯软件武装，无 `EXTERNAL_ALLOW`，无硬件锁存 | 增加许可链与武装锁存参与 H1 |
| 9 | `main.cpp` 看门狗 | 升级条件实际不可达（要求连续 100 次超预算**且**单次 > 预算×5000），等价于从不升级 | 改用 `esp_task_wdt` 或独立硬件看门狗，超时直接进 `SAFE` |
| 10 | `main.cpp` | `FAULT` 是单一锁存，无故障码 | 定义故障码枚举，遥测结构化输出 |
| 11 | `main.cpp` `enterFault` | 绕过 `changeState`，跳过"离开 LOCKED 自动卸载武装" | 统一入口 |
| 12 | `main.cpp` `setup()` | `enterFault` 后仍继续初始化舵盘、摄像头、标定 | 初始化失败后走受限分支，不继续推进周期 |
| 13 | `main.cpp` | `enterFault` 依赖将被删除的电机 API；且开环舵机断电会让 tilt 因重力下坠 | 故障时先把舵机驱到安全位再断电，或加机械阻尼 |
| 14 | `main.cpp` `s_lock_frames` | `LOCKED` 用 100Hz 控制拍 × 8 帧 ≈ 80ms，与 §11.1 的 ≤500ms 口径不一致，不足以支撑不可逆动作 | 作为发射门时改用时间窗加多视觉帧确认 |
| 15 | `main.cpp` `shellEmergencyStop` | 急停等同 `FAULT`，方向对，但受第 1 条无恢复路径拖累 | 修好第 1 条后该映射可保留 |
| 16 | `main.cpp` `CALIB_MODE` 分支 | 用无效观测调 `turretUpdate`，缺周期上限硬约束 | 第 5、6 条修复后补上 |

### 6.10 舵机化的安全设计

**上电归零**。PWM 舵机内部有电位计，指令脉宽对应绝对角，它自身是位置闭环的。所以归零在舵机上分两种
含义：设定物理基准，以及验证装配基准没偏。真实风险是上电前被外力拨偏或装配偏差，导致指令 0° 与
物理 0° 不一致。

1. 上电时释放链先被硬件固定在禁止侧，预载使能断开。归零完成前不许改变。
2. 每轴加参考开关（`PAN_HOME`、`TILT_HOME`），以限幅速度驱向参考方向等待触发。tilt 带重力负载，
   速度要慢，允许舵机先吃掉重力。
3. 开关触发后记为物理基准，退回一个已知角度作为 `HOME`。3 秒内不触发或触发后丢失即归零失败，
   进 `FAULT`，释放链保持断开，绝不进 `READY`。
4. 归零全程区域 A 处于 `HOME`，区域 B 处于 `CALIBRATING`。
5. 归零完成后再校验标定数据，有效才进 `READY`。

不建议省掉参考开关。装配偏差与上电前被动位移是真实存在的，而释放不可逆，一次基准错误就是打错方向。

**舵机选型建议**：优先用带总线反馈的舵机，而不是经典三线 PWM 舵机。§1.1 已把云台舵机排除在 ¥50 之外，
预算不是约束。总线舵机能直接回报位置、负载、温度，把失速检测从"猜"变成"读"，也让 `PAN_HOME`/`TILT_HOME`
退化成一次上电校验。这是舵机范畴内的实现选择，不违背已冻结的决策。

**失速检测**（无编码器时）：可用电流（舵机供电轨串 I2C 电流监控，走 I2C0）、母线电压跌落、到位时间
超时、电流时间积分的热模型。策略上检测到失速不进 `FAULT`，而是先停该轴、回退、重试一次，仍失败则把
该轴标记为退化并禁止进入 `AIM_ALLOWED`（指向不可信），释放链保持断开。只有失速发生在储能态或与机构
卡死耦合时才升级 `FAULT`。现有的"速度长时间为零而 duty 高"判据在舵机上不再适用。

**状态信号选型**：

| 信号 | 推荐 | 理由与注意 |
|---|---|---|
| `MECH_RECOVERED` | 微动开关常闭干接点 | 无源、可直接串进使能路径，最 fail-safe。要实测开关力不改变复位位置 |
| `STAGE1_STATE` / `STAGE2_STATE` | 霍尔锁存 | 无接触、数字锁存无 ADC 漂移、耐灰。**磁钢会扰动 snap 动力学**，必须做带靶/不带靶的 force-displacement 对照，靶附近件用 304 不锈钢（近无磁），别用 301 |
| `MAG_HOME` | 霍尔锁存 | 旋转件上贴小磁钢最简单，无需光路对齐 |
| `MAG_INDEX_OK` / 对齐 | 霍尔锁存或光电对射 | 对齐是安全相关，要接进与门 |
| `PAN_HOME` / `TILT_HOME` | 总线舵机位置加一个校验开关 | 有总线舵机时开关只做上电校验；PWM 舵机时开关是唯一基准 |

任何加到运动件上的传感靶都会改变动力学，§22.2 要求模块可拆可测，所以靶要能旋拧拆下，方便对照实验。
这一条必须实验确认，不能在设计上拍板。

### 6.11 最需要先验证的三件事

1. **释放路径的硬件门控能否在火柴盒体积内落地，且失败时确实落到禁止侧。** 整套安全设计的重心在 H1。
   先把释放执行器的原理定下来（电磁铁、sear 释放、还是预载反向），再证明与门可行、断线可测、
   MCU 卡死也放不出。验证方式：搭一块只有释放链和与门的小板，逐条故意断开输入、故意让 MCU 输出常高，
   确认释放无动作。这条不通过，后面所有状态机都是纸面。
2. **两级 snap 相对单级的实际动态价值。** 这是 §14、§30 STOP-01/02、§35 的核心问题。若单级相对普通
   膜片无可测优势，或双级更差，`PRELOAD → ARMED → RELEASE → RECOVER` 这条链与旋转供给盘的必要性都会塌掉。
   先做 §16 的 A1/B1/C1 对照，拿到可重复的 force-displacement 与脉冲时间曲线，再决定要不要把储能与
   释放链做进状态机。
3. **开环舵机的上电归零可靠性与失速可检测性。** 归零不可靠会让系统朝错误方向释放，失速检测不了会烧
   舵机或让云台静默失位。验证方式：测候选舵机参考开关的重复定位精度（多次上电的零位散布），做定角
   阶跃记录电流波形并标定堵转阈值，确认"电流超限且持续"不误报不漏报。

另有一条需要在 H1 定型时一并确认：**`ARMED` 态能否安全卸载**。如果机构一旦储能就只能释放、没有安全
dump 通道，`ARMED` 期间的任何中止都只能停在 `FAULT` 并保持硬件断开，这会显著改变状态机的可用性。
这个机械能力要在 A/B/C 阶段一并验证。

---

## 7. 执行机构变更

| 项 | 第一期 | 第二期 |
|---|---|---|
| 云台 | JGB37-520 12V 减速电机 ×2 + TB6612FNG + 霍尔编码器 + 双环 PID | 微型舵机 ×2，位置指令 |
| 反馈 | 编码器闭环 | 无编码器，靠 `PAN_HOME` / `TILT_HOME` 归零 |
| 发射 | `Transmitter` 抽象（arm/fire/急停） | 扩展为 `BOUNDARY` / `PRELOAD` / `RELEASE` / `MAG_INDEX` 四路 |
| 校准 | 像素到角度的仿射标定 | 保留，外加舵机的零点与行程标定 |

电机闭环那一层（`motor_driver`、`encoder`、`axis`、`turntable` 的双环 PID）在第二期删除。
删除会带走两个能力：编码器反馈带来的低速平滑性，以及基于角速度实测的提前量收敛。
舵机开环后，提前量只能靠标定得到的延迟常数补偿，精度会下降。这是体量换来的代价，接受。

`math/angle_utils` 与 `math/pid` 保留：角度环绕逻辑仍然需要，第二期的舵机行程标定与限幅也用 PID 的限幅部分。

---

## 8. 原型路线

规格书 §13 定死 A → B → C → D → E，§14 要求不得跳级。每一级只有达标才继续。

| 级 | 内容 | 与第一期代码的关系 |
|---|---|---|
| **MST-01A** | 普通膜片基线，无 snap | 用第一期的云台与状态机做联调平台 |
| **MST-01B** | 单级 snap | 增加 `STAGE1_STATE` 采集 |
| **MST-01C** | 双级串联 snap | 增加 `STAGE2_STATE`，要判定两级顺序与间隔 |
| **MST-01D** | 可切换边界研究版 | 增加 `BOUNDARY_CMD` 与边界状态记录 |
| **MST-01E** | 自动供给完整版 | 增加 `MAG_*` 全部信号与索引流程 |

§30 的 STOP 条件要在软件里落地：哪些该让系统进 FAULT，哪些只是记录并降级。这一条由第 6 节的评审决定。

---

## 9. 待验证的高风险项

按 §1.1 的优先级（安全 > 可重复性 > 可靠性 > 小型化 > 低成本 > 输出强度）排序。

1. **视觉循环与发射时序的隔离**。单片方案下两者共用一个 CPU。如果 `PRELOAD`/`RELEASE` 的时序被视觉
   处理拖后，轻则脉冲不一致，重则机构停在中间态。第二期必须实测最坏情况下的时序抖动。
2. **舵机开环的指向精度**。失去编码器后，舵机的死区、回差、温漂都直接进入瞄准误差。要在 MST-01A
   阶段就量出静态指向重复性，确认还能不能把目标锁在画面死区内。
3. **`MECH_RECOVERED` 的判定可靠性**。这是 Interlock 1 的唯一依据，如果它误报为真，系统会在机构未复位时
   进入 PRELOAD。用一个慢速 I2C 扩展器读它是否够快、够可靠，要在 MST-01B 验证。

---

## 10. 交付物清单

规格书 §33 要求的全部文件，加上第一期已产出的：

```
REQUIREMENTS.md              SYSTEM_ARCHITECTURE.md       INTERFACES.md
DESIGN_DECISION_LOG.md       BOM.csv                      RISK_REGISTER.md
TEST_PLAN.md                 FAILURE_MODES.md             STATE_MACHINE.md
DATA_SCHEMA.md               MST-01A ~ E CAD
```

第一期已交付：`05_FIRMWARE/algo_reference/` 算法参考实现、`05_FIRMWARE/` 固件、
`07_EXPERIMENTS/tools/` 标定与评估工具链，以及 `02_REQUIREMENTS/` 下的设计、推导、接线三份文档。

---

## 11. 变更记录

| 日期 | 变更 |
|---|---|
| 2026-09-13 | 初版。确立"一件产品两期做"；执行机构改微型舵机并删除电机闭环；引脚重算后改为单片 MCU + I2C 扩展；状态机与互锁待独立评审 |

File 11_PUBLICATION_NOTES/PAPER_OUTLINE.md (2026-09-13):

# 论文提纲

本文件给出一篇论文的骨架。实验还没有做，第 5 节的结果部分是一份待填的图表清单，逐条注明由哪个实验或
哪个模型产出、数据文件在仓库的哪个路径。清单里没有任何编造的数字。关键词按规格书 §24 列。

引用来源统一用 `01_PRIOR_ART/SOURCE_DIGEST.md` 的 SRC-/PAT- 编号，prior-art 的技术元素与证据对应关系
直接引 `01_PRIOR_ART/CLAIM_MATRIX.md`，不另行编号。数据引用 `08_DATA/`，图引用 `09_PLOTS/`，本目录不另存。
对外提交前按 `README.md` 的约定把安全互锁的具体接法拿掉。

## 0. 题名与关键词

题名沿研究问题的口径，建议围绕"串联弹性失稳机构与被动膜片的瞬态脉冲耦合"，不要出现武器或杀伤相关词。
关键词取 §24：

- sequential elastic instability
- snap-through
- transient impulse shaping
- diaphragm coupling
- compact compliant actuator
- nonlinear mechanics
- tunable boundary conditions

## 1. 问题

问题陈述用 §24 的正确表述：研究紧凑串联弹性失稳机构与膜片负载耦合后，边界状态、级间非线性和膜片柔度
如何共同影响瞬态机械脉冲的形成。不需要实验回答的版本见 §35（本文提纲不重复，引用即可）。本节要交代
三点：现有 sequential snap 与 snap 流体脉冲的研究已经很多（第 2 节展开）；缺的是多级非线性核心直接
耦合被动膜片后的动态规律；本文用 A/B/C 三级对照去回答单元数量、边界状态、预载、膜片柔度各自贡献了什么。

## 2. 相关工作

按 `CLAIM_MATRIX.md` 的技术元素组织，每段末尾用证据编号收口。分五块：

多级失稳与可编程响应。SRC-01、SRC-02、SRC-03、SRC-04。已覆盖多个失稳单元串联、多阶段力—位移曲线、
失稳顺序可调、locked / released 边界刚度调节。本文与这一块的区别只在"这些机制作用到被动膜片后的动态
结果"，且这层还是待验证。

失稳到流体脉冲。SRC-05 把 snap-through 与 pulsatile pumping 连起来，PAT-01 用膜片 snap 产生短空气脉冲
（1994 优先权），PAT-02 用失稳式空气脉冲推动软质载荷（2007 优先权）。这一块已经把"弹性能转成空气脉冲
再作用到软载荷"封死。本文的膜片只作被动负载，驱动的来源是多级机械核心，这两点的组合是待研究的点。

膜片与阀。SRC-06 是双稳软膜气动开关。本文的膜片不承担开关功能，只把机械位移转成短时空气体积位移，
相关工作段要明确切分。

柔顺机构与小型化。SRC-07 的单体柔顺发射器与尺度规律、PAT-06 的 MEMS 双稳机构。小型化本身不是贡献，
只能在方法里作为工程约束出现。SRC-08 说明双稳态弹射小物体也已有先例。

供给系统。PAT-03、PAT-04、PAT-05 覆盖气动旋转索引、电机旋转软镖弹仓、软弹加弹仓。MST-01E 的旋转盘是
工程实现，写进系统描述，不写进贡献。

本节的收尾一段，把 `CLAIM_MATRIX.md` 末三行原样带出，说明本文的候选贡献落在这三个点上，并写明离线
资料未包含完全同构单一来源、系统级组合待验证。

## 3. 方法

本节要让人看出软硬件资产是真做出来的东西，逐项给出仓库路径。

### 3.1 参数化机械设计与构件

尺寸与布局集中在 `03_CAD/lib/params.py`，参数来源登记在 `PARAM_SOURCES`。几何模块分 FRAME、STAGE_1 /
STAGE_2（von Mises truss，弹性片为独立件，见 `03_CAD/lib/stage.py`）、DIAPHRAGM_MODULE
（`03_CAD/lib/membrane.py`）、RELEASE_MODULE（自锁卡榫加电磁铁拔销，`03_CAD/lib/release.py`）。
A/B/C 三级各自有 `build.py` 装配并做几何自检，导出的 STL 在 `03_CAD/MST-01A/exports/`、
`03_CAD/MST-01B/exports/`、`03_CAD/MST-01C/exports/`。B 级比 A 级多 STAGE_1 与 RELEASE_MODULE，
C 级比 B 级多一个 STAGE_2 和级间垫片 `STAGE_GAP_shim.stl`。失稳单元几何是 a=8 mm、L=10 mm、h0=6 mm，
与 `04_SIMULATION/models/params.py` 的 `A_VMT` / `L_VMT` 对齐。三级轴向长度分别为 32 / 38 / 44 mm，
落在 §1.2 envelope 内。

### 3.2 释放门控硬件

`03_CAD/electronics/` 是释放路径的硬件门控板。`release-gate.kicad_sch` 与 `release-gate.kicad_pcb`
给出原理图与板图，导出件为同目录 PDF / SVG，物料在 `bom.csv`，板级验证步骤在 `test-procedure.md`。
逻辑是两级与门树 Q1 / Q2（一片 74HC21），加 74HC123 单稳态把释放脉宽钳在约 33 ms，74HC74 做故障锁存与
武装锁存。这一块把架构 §6.6 的 H1 到 H6 做成实体，对应 §10.3 的 `RELEASE_CMD` 与 §11 的四条互锁。
方法一节要说明 MCU 只发状态与释放请求，物理门控独立于固件，芯片卡死也放不出一次释放。

### 3.3 固件与状态机

固件工程在 `05_FIRMWARE/`，PlatformIO + Arduino + C++17，主控 ESP32-S3。状态机做成双区域：区域 A 管发射
周期，区域 B 管指向质量，跨区域用守卫矩阵约束，细节见 `05_FIRMWARE/state-machine.md`。软件互锁在
`05_FIRMWARE/src/hal/safety_gate.*`，是硬件与门之外的第二层。故障码与软硬分级见
`05_FIRMWARE/fault-codes.md`。遥测按 §19 的 17 个字段输出，格式在 `05_FIRMWARE/README.md` 第 4 节。
论文里报告的是第二期执行层：`BOUNDARY` / `PRELOAD` / `RELEASE` / `MAG_INDEX` 四路命令，与
`STAGE1_STATE` / `STAGE2_STATE` 两路事件捕获。

### 3.4 数值模型

`04_SIMULATION/` 是纯 Python 与 numpy 的力学模型，不依赖有限元软件与 scipy。膜片用 Föppl 大挠度薄膜
理论的单模态近似（`models/membrane.py`），失稳单元用经典 von Mises truss 势能加可滑动底端的边界弹簧
（`models/vmt.py`），A/B/C 都装配成一维串联链（`models/chain.py`），准静态用位移控牛顿法、瞬态用速度
Verlet 辛积分（`models/solver.py`）。三个 study 对应 §23.1 准静态、§23.2 瞬态、§23.3 参数扫描，见
`studies/quasi_static.py`、`studies/transient.py`、`studies/parameter_study.py`。模型的假设、局限与
参数出处写在 `04_SIMULATION/README.md`，论文里要如实转述，尤其是忽略气腔与流体耦合、材料粘弹这两条。

### 3.5 实验方法

实验纪律与通过标准见 `07_EXPERIMENTS/TEST_PLAN.md`。测量链是力传感器、位移传感器或高速视频、低量程
压力传感器、事件 GPIO 中断、高速视频。执行次序固定 A → B → C → D → E，每级达标才进下一级（§14、
REQ-108）。重复性口径按 TEST_PLAN 第 0.3 节。数据写入 `08_DATA/`，图从那里读。

## 4. 实验

按 TEST_PLAN 的 A 到 E 五级写，每级给进入条件、测试项、测量变量、通过标准与不通过时的处置。

- A1 普通膜片基线，无 snap（§16）。产出 A1 的力、位移、压力、视频与笔记。
- B1 单级 snap，与 A1 对照（§16）。判定方向：膜片响应是否明显更快、是否可重复、振铃是否过大。
  不通过触发 STOP-01。
- C1 双级串联 snap（§16）。判定两个事件是否可分辨、顺序是否固定、是否偶发同时 snap、是否比 B 更有价值。
  不通过触发 STOP-02。
- D1 边界变化，至少 BOUNDARY_0 与 BOUNDARY_1 两个状态（§16）。不通过触发 STOP-03。
- E 级：M1 供给盘连续 50 次索引（§18）作为前置，E1 是派生的完整周期集成测试（§9.2）。卡料失败按
  STOP-04。
- 循环寿命按 100 / 500 / 1000 阶梯（§17）。

## 5. 结果（待填图表清单）

实验数据尚未产出。下表的实验数据文件路径按 `07_EXPERIMENTS/TEST_PLAN.md` 定义，文件本身还不存在；
模型数据文件已经落盘，可在 `04_SIMULATION/results/` 找到。实验完成后逐条核对路径再填。

| 编号 | 内容 | 产出实验或模型 | 数据文件 |
|---|---|---|---|
| 图 1 | 三级原型装配与截面 | CAD 模型（待渲染） | `03_CAD/MST-01A/exports/MST-01A_assembly.stl`、`03_CAD/MST-01B/exports/`、`03_CAD/MST-01C/exports/MST-01C_assembly.stl` |
| 图 2 | A/B/C 准静态力—位移曲线 | 模型 + 实验 | 模型 `04_SIMULATION/results/A_force_displacement.csv`、`B_force_displacement.csv`、`C_force_displacement.csv`；实验 `07_EXPERIMENTS/A/A1_force.csv`、`07_EXPERIMENTS/B/B1_force.csv`、`07_EXPERIMENTS/C/C1_force.csv` |
| 图 3 | snap 点、稳定分支与级序 | 模型 + 实验 | 模型 `04_SIMULATION/results/C_force_displacement.csv`；实验 `07_EXPERIMENTS/C/C1_events.csv` |
| 图 4 | 边界刚度敏感性 | 模型 | `04_SIMULATION/results/boundary_sensitivity.csv` |
| 图 5 | 瞬态膜片速度与位移时间曲线 | 模型 + 实验 | 模型 `04_SIMULATION/results/transient_A.csv`、`transient_B.csv`、`transient_C.csv`、`transient_summary.csv`；实验 `07_EXPERIMENTS/A/A1_displacement.csv`、`07_EXPERIMENTS/B/B1_displacement.csv`、`07_EXPERIMENTS/C/C1_displacement.csv` |
| 图 6 | 两级事件时刻与级间时延 | 模型 + 实验 | 模型 `04_SIMULATION/results/transient_summary.csv`（`stage_interval_s`）、`04_SIMULATION/results/sweep_mismatch.csv`；实验 `07_EXPERIMENTS/C/C1_events.csv` |
| 图 7 | 低量程压力—时间 | 实验（模型暂无气腔） | `07_EXPERIMENTS/A/A1_pressure.csv`、`07_EXPERIMENTS/B/B1_pressure.csv`、`07_EXPERIMENTS/C/C1_pressure.csv` |
| 图 8 | 同条件多周期重复性叠加 | 实验 | `07_EXPERIMENTS/A/A1_displacement.csv`（每条件至少 10 次）、`07_EXPERIMENTS/B/B1_displacement.csv`、`07_EXPERIMENTS/C/C1_displacement.csv` |
| 图 9 | 边界状态对照 | 实验 | `07_EXPERIMENTS/D/D1_B0_force.csv`、`D1_B0_displacement.csv`、`D1_B0_pressure.csv`、`D1_B1_force.csv`、`D1_B1_displacement.csv`、`D1_B1_pressure.csv` |
| 图 10 | 参数扫描趋势 | 模型 | `04_SIMULATION/results/sweep_boundary.csv`、`sweep_preload.csv`、`sweep_mismatch.csv`、`sweep_membrane.csv`、`sweep_damping.csv` |
| 图 11 | 循环寿命漂移 | 实验 | `07_EXPERIMENTS/C/LIFE_100.csv`、`LIFE_500.csv`、`LIFE_1000.csv`（被测机构在 B 级时路径改到 `07_EXPERIMENTS/B/`） |
| 图 12 | 供给盘索引可靠性 | 实验 | `07_EXPERIMENTS/E/M1_index.csv` |
| 图 13 | 完整周期时序 | 实验 | `07_EXPERIMENTS/E/E1_cycle.csv`、`E1_displacement.csv`、`E1_pressure.csv` |
| 表 1 | 实验变量与观测变量 | TEST_PLAN | `07_EXPERIMENTS/TEST_PLAN.md` 第 0.2 节，字段对应规格书 §15.1、§15.2、§19 |
| 表 2 | prior-art 矩阵 | 离线台账 | `01_PRIOR_ART/CLAIM_MATRIX.md` |
| 表 3 | STOP 条件与判定 | TEST_PLAN | `07_EXPERIMENTS/TEST_PLAN.md` 的 STOP 对照表 |

## 6. 讨论

讨论分四块。

耦合结论。按第 5 节的图和表说单元数量、边界状态、预载、膜片柔度各自对脉冲时间历程的贡献，以及哪些
交互项在数据里显现。没有观测到的交互要说明是没测还是没影响。

模型与实验的差异。`04_SIMULATION/README.md` 列了模型的忽略项，气压反作用与流体耦合、材料粘弹、作动器
自身动力学是定量失真的主要来源。讨论里逐条对照，不掩盖。

失败情形。若 STOP-01 或 STOP-02 成立，按 `RESEARCH_FRAMING.md` 第 6 节的口径写。阴性结果限定在名义参数
区间，不做一般化断言。记录归到 `10_FAILURE_ANALYSIS/`。

适用边界与安全。装置只做低能量空气脉冲和超轻软载荷，不讨论伤害、穿透、射程。§28 的两张清单在这里
再执行一次，讨论段不得出现"全球首创""从未有人做过"这类措辞。

## 7. 结论

结论回答 §35 的假设：在给定参数区间里，单元数量和边界状态是否产生了稳定、可重复、可区分的脉冲时间
历程，以及相对普通驱动或单级 snap 是否有可测的工程价值。若结论是回退单级，就如实写回退；若结论支持
多级，也只写到"本离线资料未包含完全同构单一来源"，把 claim-level 查新留给后续。

## 附录 A 数据与复现

数据字段见 §19，数据文件归 `08_DATA/`，图从 `08_DATA/` 读、放 `09_PLOTS/`，不在本目录重存。模型重跑
命令见 `04_SIMULATION/README.md`，固件构建命令见 `05_FIRMWARE/README.md`，CAD 重建命令见
`03_CAD/README.md`。

## 附录 B 图表命名与状态

图只放结果，推导在 `02_REQUIREMENTS/`，模型细节在 `04_SIMULATION/`。每张图标注数据来源路径与生成脚本，
保证换个人能重画。第 5 节清单里的实验项在数据落盘前保持"待填"状态，不要预填占位数值。

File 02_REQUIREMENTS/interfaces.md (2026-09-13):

# MST-01 接口定义（interfaces.md）

本文把机械、电子、固件三方需要对齐的接口固定下来，让各自按同一份数字和极性做，装配和联调时能对上。
数据来源：主规格 §10/§11/§12/§18/§19，统一架构 §3/§4/§6/§7，`05_FIRMWARE/io-map.md` 与
`05_FIRMWARE/include/config.h`。

约定两条：

- 引脚、扩展器位、宏名以 `config.h` 为准；本文与代码不一致时算本文的缺陷，立即回填。
- 规格书和代码都没冻结的条目标"待定"，后面写清定它的前置条件，不拿猜测值当接口。

接口编号按类别分：`IF-ELEC`（对外电气）、`IF-MECH`（机械）、`IF-EXP`（扩展器）、
`IF-HOST`（上位机）、`IF-GATE`（硬件安全门）。

---

## 1. 对外电气接口（IF-ELEC）

### 1.1 电源输入

整机分三条轨：执行轨（舵机与释放执行器）、逻辑轨（3.3V 主控与传感）、辅助轨（5V，摄像头或部分舵机）。
执行轨和逻辑轨分开供电，只在一点共地。

| 项目 | 规格 | 状态与前置条件 |
|---|---|---|
| 主输入电压 | 待定。候选 12V DC 或 2S 锂电 7.4V | 舵机与释放执行器选型后冻结，见 `SERVO_DRIVE_TYPE` |
| 逻辑轨 | 3.3V，ESP32-S3 主控 | 由主输入降压，必须与执行轨隔离 |
| 辅助轨 | 5V | 依摄像头与舵机型号决定是否独立 |
| 峰值电流 | 待定 | 由释放执行器浪涌和舵机堵转电流决定；选型后按最坏同时动作估算，留 2 倍余量 |
| 连接器 | 待定。要求键控、防反插、带锁扣 | 逻辑轨与执行轨必须用不同型号，插错插不进 |
| 防反接 | 逻辑轨入口串肖特基或 P-MOS 理想二极管 | 执行轨若有感性执行器，反并续流二极管 |
| 短路保护 | 各轨入口串自恢复保险丝 | 参数按实测稳态与峰值电流整定 |
| 接地 | 单点共地，禁止地环路 | 电机/执行器线不得与摄像头排线并捆 |

主电源的切断由急停回路承担，不经过 MCU，见 1.2。

### 1.2 急停回路

急停用常闭蘑菇头，主触点直接串在执行轨供电里，按下即断开执行轨。这条回路不经过 MCU，也不受固件状态影响，
对应架构 §6.5 的 H6。

- 主触点：常闭，串执行轨。断路即断电。
- 辅助触点：接 MCU 或接入 `FIRE_INHIBIT` 链，让软件知道急停已动作并锁存。辅助触点只做状态感知，
  不承担断电功能。
- 线径与连接器：待定。前置条件是执行轨峰值电流定下来。
- 失效方向：回路任何断开都落到断电侧。触点粘合会让急停失效，属于单点失效，处理见
  `safety-boundary.md` 第 6 节。

### 1.3 EXTERNAL_ALLOW（上级许可）

| 项目 | 规格 |
|---|---|
| 语义 | 上级授权这一发，绿灯 |
| 电平 | 3.3V 逻辑电平 |
| 极性 | 主动驱动到高为许可 |
| 静态偏置 | 外部下拉 10kΩ 到 GND，MCP23017 内部上拉不启用 |
| 接入 | MCP23017 位 10（`EXP_EXTERNAL_ALLOW_BIT`），见第 3 节 |
| 有效窗口 | 仅在 READY/AIM_ALLOWED/PRELOAD/ARMED 期间监视；上升沿作为释放触发条件之一 |
| 双通道 | 预留。用两个冗余触点交叉校验，两路不一致按禁止处理；是否必须做双通道由安全完整性实验确认 |

### 1.4 FIRE_INHIBIT（安全否决）

| 项目 | 规格 |
|---|---|
| 语义 | 安全装置否决释放，红灯。网络名记 `FIRE_INHIBIT_N`，高电平表示"未否决、允许" |
| 来源 | 舱门开关、光幕、外接急停、机械钥匙等安全装置 |
| 电平 | 3.3V 逻辑电平 |
| 极性 | 高为未否决（允许），反转后进释放与门 |
| 静态偏置 | 外部下拉 10kΩ 到 GND，开路即否决 |
| 接入 | MCP23017 位 9（`EXP_FIRE_INHIBIT_BIT`） |
| 监视窗口 | PRELOAD 与 ARMED 期间持续监视，出现上升沿（否决生效）立即安全卸载 |
| 双通道 | 预留，理由同 EXTERNAL_ALLOW |

软件侧把原始电平取反后使用：`safetyFireInhibitAsserted()` 返回真表示否决生效。先判 `FIRE_INHIBIT`
再判 `EXTERNAL_ALLOW`，日志分开记录，事后能区分是安全装置拦截还是上级撤回授权。

### 1.5 三种失效下的行为

逐条列对外通路。短路一列区分短到允许侧（3V3）和短到禁止侧（GND），前者是危险方向，后者落安全。

| 通路 | 开路 | 掉电 | 短路 | 落点 |
|---|---|---|---|---|
| 主电源输入 | 整机断电 | 整机断电 | 输出短路由自恢复保险限流 | 断电侧，安全 |
| 急停回路主触点 | 执行轨断电 | 执行轨断电 | 触点粘合则急停失效，靠冗余或点检；短到 GND 仍断路 | 安全，粘合除外 |
| EXTERNAL_ALLOW | 下拉到低，拒绝 | 下拉到低，拒绝 | 短到 GND 仍拒绝；短到 3V3 会伪许可，需双通道检出 | 开路/掉电安全，短到 3V3 危险 |
| FIRE_INHIBIT_N | 下拉到低，否决 | 下拉到低，否决 | 短到 GND 仍否决；短到 3V3 会失去否决，需双通道与卡死诊断 | 开路/掉电安全，短到 3V3 危险 |
| RELEASE_CMD 通路 | 无请求，释放不导通 | 无请求 | 短到 GND 关断；短到 3V3 依赖硬件单稳态钳位脉冲宽度 | 开路/掉电安全，短到 3V3 需硬件兜底 |
| PRELOAD 使能通路 | 预载不动作 | 预载不动作 | 短到 GND 关断；短到 3V3 需 `MECH_RECOVERED_N` 常闭触点串接兜底 | 开路/掉电安全，短到 3V3 需硬件兜底 |

危险方向（短到允许侧）目前靠冗余触点和硬件门控兜底，安全完整性做到哪一级要实验确认。设计上先按双通道留位置。

---

## 2. 机械接口（IF-MECH）

只列跨模块配合面。规格书给的是工程 envelope，不是冻结尺寸，下面凡"待定"的都不能拿去开模或打印。

| 编号 | 接口 | 基准或要求 | 状态与前置条件 |
|---|---|---|---|
| IF-MECH-01 | 云台输出法兰与炮头安装面 | 提供安装孔阵列与定位面；两轴 0° 时炮口轴线与视觉光轴保持固定夹角 | 待定。前置条件：舵机云台选型 + CAD 冻结 |
| IF-MECH-02 | 视觉光轴与发射轴线对齐 | 装配后记录相对姿态，交给标定吸收残余偏差 | 待定。前置条件：摄像头支架与炮头装配基准冻结 |
| IF-MECH-03 | 供给盘与炮头的对接面 | 中心定位孔 + 端面贴合 + 防转键；每个 pocket 与发射孔同轴；有唯一方向防呆、零位标记、机械止挡 | 待定。前置条件：`MAG_POSITIONS` 定 6 还是 8，供给盘 CAD 冻结 |
| IF-MECH-04 | 供给盘零位靶与 `MAG_HOME` 传感器 | 零位标记与传感靶同相位，重复定位可测；靶可旋拧拆下做对照 | 待定。前置条件：`MAG_HOME` 传感器选型（霍尔锁存候选） |
| IF-MECH-05 | 载荷对齐检测靶与 `MAG_INDEX_OK` | 对齐信号是安全相关，必须接进硬件与门；模式 A 用继电器旁路为真 | 待定。前置条件：H3 与门方案冻结 |
| IF-MECH-06 | `PAN_HOME` / `TILT_HOME` 参考开关 | 开关装在固定框架上，触发件装在运动件上；位置可调，全行程不干涉；触发重复定位精度要测 | 待定。前置条件：舵机选型与装配基准冻结 |
| IF-MECH-07 | 膜片压环的拆装空间 | 不拆核心即可更换膜片；留出工具回转空间；压环可重复装拆 | 待定。前置条件：`DIAPHRAGM_MODULE` CAD |
| IF-MECH-08 | `STAGE1_STATE` / `STAGE2_STATE` 传感靶 | 磁靶会影响 snap 动力学，靶件用 304 不锈钢等近无磁材料；靶必须可拆，做带靶与不带靶的 force-displacement 对照 | 待定。前置条件：A1/B1/C1 对照实验确认扰动可接受 |
| IF-MECH-09 | 释放执行器与脉冲核心的机械耦合 | 释放执行器（电磁铁、sear 或预载反向）与两级核心接口对齐 | 待定。前置条件：架构 §6.11 第 1 项 H1 定型 |
| IF-MECH-10 | 两轴机械止挡 | 物理止挡是末端防线，软限位必须提前生效 | 待定。前置条件：舵机行程标定（`SERVO_PAN_MIN/MAX_DEG` 等） |

`REQ-127` 要求 CAD 至少拆成 FRAME、STAGE_1、STAGE_2、BOUNDARY_MODULE、DIAPHRAGM_MODULE、PAYLOAD_MODULE、
MAGAZINE_MODULE 七个模块，上表的配合面都落在模块边界上。

---

## 3. 固件与扩展器的接口（IF-EXP）

片内 GPIO 已分配完，慢速离散 I/O 全部走一片 MCP23017。

### 3.1 总线与器件

| 项目 | 值 | 来源 |
|---|---|---|
| 总线 | I2C0 | `config.h` |
| SDA / SCL | GPIO45 / GPIO46（strapping 脚，上电电平必须核对） | `I2C0_SDA_PIN` / `I2C0_SCL_PIN` |
| 速率 | 400 kHz | `I2C0_FREQ_HZ` |
| 从地址 | 0x20（A2A1A0 全低） | `MCP23017_ADDR` |
| 寄存器布局 | IOCON = 0，BANK = 0，地址自动递增 | `io_expander.cpp` |
| 事务超时 | 20 ms | `io_expander.cpp` |
| 内部上拉 | 不启用，上拉/下拉全部外置 | `io_expander.cpp` |
| 读失败行为 | 返回 0 并把健康标志置假 | `ioExpanderReadInputsSnapshot` / `ioExpanderHealthy` |
| 输出上电默认 | 全 0（BOUNDARY/PRELOAD/MAG_INDEX 断，STATUS_LED 灭） | `io_expander.cpp` |

### 3.2 位分配

位编号 0-7 = GPA0-GPA7，8-15 = GPB0-GPB7。方向、极性、上电默认如下。输出掩码 `EXP_OUTPUT_MASK`
只含位 0 到 3，其余配置为输入。

| 位 | 名称 | 宏 | 方向 | 有效极性 | 上电默认 | 说明 |
|---:|---|---|---|---|---|---|
| 0 | `BOUNDARY_CMD` | `EXP_BOUNDARY_CMD_BIT` | 输出 | 高 = 激活边界状态 | 0 | 慢速，边界研究，`MST_BOUNDARY_RESEARCH_ACTIVE` 控制是否置起 |
| 1 | `PRELOAD_CMD` | `EXP_PRELOAD_CMD_BIT` | 输出 | 高 = 预载 | 0 | 硬件串 `MECH_RECOVERED_N` 常闭触点 |
| 2 | `MAG_INDEX_CMD` | `EXP_MAG_INDEX_CMD_BIT` | 输出 | 高 = 索引一步 | 0 | 慢速 |
| 3 | `STATUS_LED` | `EXP_STATUS_LED_BIT` | 输出 | 高 = 亮 | 0 | 指示 |
| 4 | `MAG_HOME` | `EXP_MAG_HOME_BIT` | 输入 | 高 = 触发 | 读入 | 供给盘零位 |
| 5 | `MAG_INDEX_OK` | `EXP_MAG_INDEX_OK_BIT` | 输入 | 高 = 到位/对齐 | 读入 | 对齐检测并入本通道（C-11） |
| 6 | `MECH_RECOVERED` | `EXP_MECH_RECOVERED_BIT` | 输入 | 低 = 已复位 | 读入 | 常闭干接点对地，外部上拉；`safety_gate` 取反后使用 |
| 7 | `PAN_HOME` | `EXP_PAN_HOME_BIT` | 输入 | 高 = 触发 | 读入 | pan 参考开关 |
| 8 | `TILT_HOME` | `EXP_TILT_HOME_BIT` | 输入 | 高 = 触发 | 读入 | tilt 参考开关 |
| 9 | `FIRE_INHIBIT` | `EXP_FIRE_INHIBIT_BIT` | 输入 | 高 = 未否决/允许 | 读入 | 外部下拉，开路即否决 |
| 10 | `EXTERNAL_ALLOW` | `EXP_EXTERNAL_ALLOW_BIT` | 输入 | 高 = 许可 | 读入 | 外部下拉，开路即拒绝 |
| 11-15 | 预留 | 无 | 输入 | 按信号定义外置偏置 | 读入 | 未分配 |

### 3.3 读写模型

固件每拍调一次 `safetyGateUpdate()`，它内部通过 `ioExpanderReadInputsSnapshot()` 一次事务读完 16 位，
再用 `ioExpanderHealthy()` 确认这同一次事务成功，避免逐位读取时口径不一致。总线失败时
`safety_gate` 走 `forceSafe()`，把全部输入按禁止侧解释，不允许"读不到就默认机构已复位"。

输出写通过 `ioExpanderWritePin()`，写失败只记录健康标志，不清除已写值，影子寄存器保留末次写入的位型。
这一点在 `safety-boundary.md` 第 6 节作为单点失效讨论。

### 3.4 已知文档冲突（不改文件，先记录）

- `config.h` 第 181 行注释写"其余为输入并启用内部上拉"，与 `io_expander.cpp` 显式关闭内部上拉
  矛盾。以 `io-map.md` 和 `io_expander.cpp` 为准，`config.h` 该行注释需要更新。
- `io_expander.cpp` 头注释把 `MECH_RECOVERED` 写成"断言为高"，与 `safety_gate.cpp`
  的取反逻辑及 `io-map.md` 的"复位时为低"矛盾。以 `safety_gate.cpp` 和 `io-map.md` 为准。
- `io-map.md` 第 7 节把 `CAL JOG` 描述为"走双环 PID"，`calib_shell.cpp` 第 145 行帮助文本
  同误，二期已删除 PID 层，应改为限幅与变化率限制。

---

## 4. 固件与上位机的接口（IF-HOST）

### 4.1 串口参数

| 项目 | 值 |
|---|---|
| 端口 | UART0（`DEBUG_TX` 预留可映射到 USB CDC，见 C-10） |
| 波特率 | 115200（`TELEMETRY_BAUD`） |
| 帧格式 | 8N1 |
| 行分隔 | `\n`；命令接受 `\r\n` |
| 命令大小写 | 不敏感 |
| 单行上限 | 96 字符，超长整行丢弃并回 `ERR` |
| 逐帧遥测开关 | `AIM_VERBOSE_TELEMETRY`；关闭时只发 1 Hz 心跳（`TELEMETRY_HEARTBEAT_MS`） |

### 4.2 遥测数据行

前缀 `MST,`，字段与顺序按主规格 §19，共 17 个，字段名和顺序不可改。字符串字段不得含逗号。

| # | 字段 | 类型 | 单位 | 取值范围 | 说明 |
|---:|---|---|---|---|---|
| 1 | `timestamp` | uint32 | ms | 0 .. 4294967295 | 毫秒时间戳，会回绕 |
| 2 | `experiment_id` | uint16 | 无 | 0 .. 65535 | `MST_EXPERIMENT_ID` |
| 3 | `prototype_version` | string | 无 | 不含逗号 | 如 `MST-01C` |
| 4 | `mechanism_version` | string | 无 | 不含逗号 | 机制变体 |
| 5 | `mode` | uint8 | 无 | 0 / 1 | 0 = Mode A 空气，1 = Mode B 软载荷 |
| 6 | `boundary_state` | uint8 | 无 | 0 / 1 | `BOUNDARY_0` / `BOUNDARY_1` |
| 7 | `preload_state` | uint8 | 无 | 0 / 1 / 2 | 0 空闲，1 预载中，2 已武装 |
| 8 | `membrane_id` | uint16 | 无 | 0 .. 65535 | 膜片批次或试样编号 |
| 9 | `payload_id` | uint16 | 无 | 0 .. 65535 | 载荷批次或编号 |
| 10 | `cycle_count` | uint32 | 次 | 0 .. 4294967295 | 完成索引的动作计数 |
| 11 | `stage1_event` | uint8 | 无 | 0 / 1 | 本周期是否捕获到 Stage 1 |
| 12 | `stage2_event` | uint8 | 无 | 0 / 1 | 本周期是否捕获到 Stage 2 |
| 13 | `mechanism_recovered` | uint8 | 无 | 0 / 1 | 机构复位确认 |
| 14 | `magazine_position` | uint8 | 无 | 0 .. 5 | 当前工位，`MAG_POSITIONS` 为 6 |
| 15 | `magazine_index_ok` | uint8 | 无 | 0 / 1 | 索引到位 |
| 16 | `fault_code` | uint16 | 无 | 0 .. 14 | `FaultCode` 整数值，定义见 `aim_types.h` |
| 17 | `operator_note` | string | 无 | 不含逗号，默认 `-` | 操作备注 |

事件行与数据行用不同前缀区分：`EVT,<t_ms>,<tag>,<msg>`，`t_ms` 为毫秒，`tag` 与 `msg` 不含逗号。

### 4.3 标定外壳命令集

与遥测共用 115200 的 Serial，每行一条命令，参数空格分隔。响应前缀为 `OK,`、`ERR,`，以及
`ST,` / `PT,` / `SOLVE,` / `LIST,` / `LOAD,` / `CMD,` 等字段前缀。

| 命令 | 作用 | 关键约束 |
|---|---|---|
| `HELP` | 列出全部命令 | 无 |
| `STATUS` | 打印区域 A/区域 B 状态、故障码、两轴角度与标定 | 无 |
| `CAL START` | 进入手动标定模式 | 仅 READY 可用；释放链强制断开 |
| `CAL JOG <pan_deg> <tilt_deg>` | 设两轴目标角 | 越界夹到机械限位并回报；走限幅与变化率限制 |
| `CAL MARK [label]` | 记录当前有效像素观测与当前实际角 | 无效观测拒绝记录 |
| `CAL LIST` | 列出点表 | 最多 32 点 |
| `CAL DEL <n>` | 删除第 n 个点 | 序号从 1 开始 |
| `CAL CLEAR` | 清空点表 | 无 |
| `CAL SOLVE` | 最小二乘解算，报告训练与留出 RMSE | 至少 3 点；按顺序每第 3 点留出 |
| `CAL SAVE` | 把当前仿射写入 NVS | 仿射无效则拒绝 |
| `CAL LOAD` | 从 NVS 读回并应用 | 无记录则报错 |
| `CAL EXIT` | 退出标定模式 | 无 |
| `ESTOP` | 切断舵机与释放链并锁存 FAULT | 无条件立即生效 |
| `CLEAR` | 清除软故障并送 SAFE，随后自动重新 HOME | 硬故障无效 |

上位机脚本在 `07_EXPERIMENTS/tools/`，解析这些行，改动字段或命令集必须同步改脚本，见第 6 节。

---

## 5. 固件与硬件安全门的接口（IF-GATE）

释放路径的物理门控由一块与门树实现，软件 `safety_gate` 只是第二层，不替代硬件。

### 5.1 与门树

```
Q1 = AND( FIRE_INHIBIT_N, EXTERNAL_ALLOW, MECH_RECOVERED_N, POCKET_ALIGNED_or_MODE_A )
Q2 = AND( Q1, ARMED_LATCH, MCU_RELEASE_CMD, MASTER_ENABLE )
Q2 -> 负载开关使能 -> 释放执行器供电
```

器件与实现要点见架构 §6.6：一片 74HC21 双 4 输入与门级联即可覆盖；每个输入按极性加下拉或上拉，
开路即安全侧；Q2 输出加下拉，浮空等于关断；释放命令经 74HC123 单稳态钳位脉冲宽度，即使 MCU 卡在
输出高也只放一个固定短脉冲；负载开关用低边 N-MOSFET 串回流路径，栅极下拉，感性负载反并续流二极管，
串自恢复保险丝。

### 5.2 参与与门的信号

| 信号 | 作用 | 极性（有效侧） | 软件侧对应 |
|---|---|---|---|
| `FIRE_INHIBIT_N` | 安全否决，任一红灯亮即断开 | 高 = 未否决 | `safetyFireInhibitAsserted()`（取反） |
| `EXTERNAL_ALLOW` | 上级许可，绿灯 | 高 = 许可 | `safetyExternalAllow()` |
| `MECH_RECOVERED_N` | 机构复位确认 | 高 = 已复位（节点取自常闭/反相触点，命名里的 N 指此意，进与门前按高为允许接入） | `safetyMechRecovered()` |
| `POCKET_ALIGNED` | Mode B 载荷对齐；Mode A 由继电器旁路为真 | 高 = 对齐 | `safetyMagIndexOk()`（对齐检测并入 `MAG_INDEX_OK`，C-11） |
| `ARMED_LATCH` | 武装锁存，防止未武装时误放 | 高 = 已武装 | `safetyLatchArmed()` / `safetyArmedLatched()` |
| `MCU_RELEASE_CMD` | 释放请求 | 高 = 请求 | `digitalWrite(RELEASE_CMD_PIN, HIGH)`，`advanceCycle()` 的 ARMED 分支 |
| `MASTER_ENABLE` | 主使能，人工总开关或钥匙 | 高 = 有效 | 暂无对应宏与引脚，待定 |

`FIRE_INHIBIT_N` 与 `MECH_RECOVERED_N` 命名里的 N 表示取自常闭或反相节点，在与门树里都按高电平为允许侧接入。
具体电平方向在 H1 台架联调时用万用表逐点确认并回填本文。

### 5.3 预载路径的第二道硬件

预载使能串 `MECH_RECOVERED_N` 常闭触点，机构未复位时预载执行器物理上无法被驱动（H2）。软件侧由
`safetyCanEnterPreload()` 复查，只用于迁移判定与日志。

### 5.4 释放门控自检

`safetyReleaseGateSelfTest()` 确认扩展器健康且未武装时 `safetyCanRelease()` 为假。这是软件自检，
与门本身的验证要在台架上逐条断开输入、故意让 MCU 输出常高，确认释放无动作，方法见架构 §6.11。

### 5.5 代码里尚未落地的接口

`MASTER_ENABLE` 与 `POCKET_ALIGNED` 目前没有独立宏或引脚，`POCKET_ALIGNED` 走 `MAG_INDEX_OK` 合并通道，
`MASTER_ENABLE` 只存在于硬件与门树。两条的状态都是待定，前置条件是 H1 定型。

---

## 6. 接口变更流程

改任一接口，必须在同一次提交里改齐下游文件，不允许接口文档和代码各说各话。

| 改动对象 | 必须同步 |
|---|---|
| 任一 `*_PIN` 宏 | `config.h` → `io-map.md` 第 1 节 → `硬件接线与选型.md` 第 2 节 → 本文 §1/§3 |
| 任一 `EXP_*_BIT` 或输出掩码 | `config.h` → `io-map.md` 第 2 节 → 本文 §3 → `safety_gate.cpp` 的位解释 |
| 遥测字段或顺序 | `telemetry.h` / `telemetry.cpp` → `REQUIREMENTS.md` REQ-124 → 本文 §4 → `07_EXPERIMENTS/tools/` 解析脚本 |
| 标定命令集或响应格式 | `calib_shell.cpp` / `calib_shell.h` → `io-map.md` 第 7 节 → 本文 §4 → `07_EXPERIMENTS/tools/` |
| 与门树或信号极性 | 统一架构 §6.6/§6.7 → `safety_gate.cpp` / `safety_gate.h` → `main.cpp` 释放分支 → 本文 §5 → `safety-boundary.md` |
| 机械配合面或基准 | `03_CAD/` → 本文 §2 → `方案设计.md` 坐标与角度约定 |
| 接口新增或删除 | 本文 → 对应源文件 → `REQUIREMENTS.md` 的需求条目 |

下游文件没改完之前，接口改动不算完成。发现本文与代码不一致时，先以代码为准恢复一致性，再更新本文。

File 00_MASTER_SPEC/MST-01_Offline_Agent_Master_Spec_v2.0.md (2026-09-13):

# MST-01 微型定向低能量脉冲平台
# Offline Agent Master Specification / 离线 Agent 完整交接文档

> **版本**：v2.0  
> **日期**：2026-09-13  
> **状态**：方案收敛、证据修订、可交给完全不联网的 Agent  
> **阅读要求**：Agent 必须从头到尾读完本文件后再开始工作。  
> **外部依赖**：无。理解项目、做第一轮机械设计、仿真规划、控制接口和实验规划，不需要访问互联网，也不需要向用户补充询问。  
> **特别说明**：本文件已经纠正 v1.0 中把“打蚊子”误解为实际用途的问题，也修正了 v1.0 对“可变边界 + 串联 snap-through”新颖性的过高判断。  

---

# 0. 先读这一页：项目到底是什么

## 0.1 用户真正想做的东西

用户想做的是一个：

- **很小**；
- **有炮台/云台式外形和指向能力**；
- **由单片机系统控制**；
- **动作很快**；
- **机械炮头尽量低成本**；
- **发射/脉冲执行原理希望有研究新意**；

的微型定向执行平台。

用户之前说“类似打蚊子”，**“打蚊子”只是为了表达体量、自动指向和动作形式的类比，不是实际用途**。

### “打蚊子”不是项目需求

本项目：

- 不以蚊虫为目标；
- 不要求蚊虫识别；
- 不要求翼频检测；
- 不要求计算机视觉；
- 不要求自动找虫；
- 不要求研究杀虫方法；
- 不应该把任何蚊虫论文、Photonic Fence、IR 翼频分类等内容作为项目设计依据。

**任何 Agent 不得再次把“打蚊子”当作实际应用场景。**

如果需要一句最准确的项目描述：

> **MST-01 是一个 MCU 可控制、火柴盒级、低能量、可模块化供给超轻软载荷的二维指向式快速机械脉冲执行平台。**

---

# 0.2 “炮台”一词的含义

本文沿用“炮台/炮头”只是为了沟通方便。

工程上应理解为：

> **directed low-energy impulse platform / 定向低能量脉冲平台**

不是以伤害、穿透、最大射程或高速度为目标的武器系统。

---

# 0.3 安全与设计边界

本项目允许：

- 纯空气脉冲；
- EVA / EPP / 毛毡 / 轻纸质等超轻软载荷；
- 低能量近距离封闭实验；
- 机构动力学、顺序失稳、脉冲整形研究；
- 自动索引供给；
- MCU 状态控制。

本项目不允许：

- 金属弹丸；
- 玻璃/陶瓷弹丸；
- 硬质高密度实心塑料弹丸；
- 针、箭、飞镖、尖锐载荷；
- 火药、爆燃、燃烧推进；
- 高压储气瓶；
- 以提高伤害、穿透或最大射程为优化目标；
- 人体或动物测试。

设计优先级固定为：

> **安全 > 可重复性 > 可靠性 > 小型化 > 低成本 > 输出强度**

---

# 1. 冻结的用户约束

## 1.1 成本

用户给出的 **¥50** 约束，只针对：

> **炮头机械架构本身**

### 计入 ¥50

- 弹性片；
- 柔性膜片；
- 轴、销、铜套、小轴承；
- O 型圈、密封件；
- 磁铁；
- 紧固件；
- 低密度软载荷；
- 非打印的小型机械件。

### 不计入 ¥50

- MCU；
- 主控板；
- 传感器后台；
- 云台舵机；
- 云台电机；
- 发射/蓄能所用外部执行电机或舵机；
- 电源；
- PCB；
- 线材；
- 通信模块；
- 3D 打印材料成本；
- CAD/仿真/实验仪器成本。

因此：

> **不要为了省 MCU、舵机或打印材料去破坏机械方案。**

---

# 1.2 尺寸

目标不是一个固定的毫米数字，而是：

> **尽可能小，并保持可靠。**

建议目标：

- 核心脉冲模块：约 **30–50 mm 长度级**；
- 核心横向尺寸：约 **15–25 mm 级**；
- 加供给模块后允许略大；
- 整体仍属于掌心/火柴盒级微型装置。

这些数字是**工程 envelope**，不是冻结尺寸。

如果 Agent 的仿真表明更大 10–20% 可以显著提升可靠性，可以先做可靠原型，再缩小。

---

# 1.3 控制

单片机是系统控制核心。

但 MCU 不应该承担“直接产生高速机械动作”的任务。

原则：

> **MCU 控制状态，机械结构产生快速动作。**

MCU 负责：

- 归零；
- 瞄准接口；
- 机械预载状态；
- 边界状态；
- 触发许可；
- 状态检测；
- 供给索引；
- 故障锁定；
- 循环计数；
- 日志。

---

# 2. v1.0 必须修正的两个错误

## 2.1 错误一：把“打蚊子”当作应用

错误。

用户只是类比。

### v2.0 处理

删除：

- 蚊虫检测设计；
- IR 翼频传感；
- Photonic Fence；
- 蚊虫分类；
- 目标生物特性。

这些内容不再属于项目。

---

## 2.2 错误二：高估“可变边界 + 串联 snap-through”的新颖性

v1.0 曾将：

> 可变边界 + 串联失稳

作为较强候选创新核心。

这不够严谨。

### 已发现的直接证据

2026 年 Filipe A. Santos 的论文：

**3D-Printed Serial Snap-Through Architectures for Programmable Mechanical Response**

已经明确公开：

- 两到四个串联 von Mises truss bistable units；
- sequential snap-through；
- programmable multistage response；
- 每个单元有 sliding support；
- 支撑可以 locked / released；
- 通过改变 boundary stiffness 改变 snap-through 和 post-snap 行为；
- 通过 geometry、engagement gap、support constraint 调整整体响应。

因此：

> **“串联 snap-through + 可切换边界条件”本身不能作为 MST-01 的新颖性核心。**

这是 v2.0 最重要的修正之一。

---

# 3. 当前最终工程基线

虽然单个元素都有 prior art，仍然保留下面架构作为**工程/研究验证基线**：

> **低速预载 → 两级串联失稳 → 直接机械耦合柔性膜片 → 瞬态低能量空气脉冲**

并支持：

- Mode A：纯空气脉冲；
- Mode B：超轻软质载荷；
- 可拆旋转供给盘；
- MCU 状态控制。

为什么仍然做它：

1. 尺寸适合；
2. 成本低；
3. 易于 A/B 测试；
4. 有明确可测力学变量；
5. 可以验证“多级失稳对脉冲波形是否真的有价值”；
6. 即便最后专利新颖性不足，也仍可以形成机械研究数据。

### 关键态度

**它是研究基线，不是已经证明的新发明。**

---

# 4. 系统总架构

```text
┌──────────────────────────────┐
│        外部上层控制/目标坐标      │
│   （具体来源不属于本项目范围）      │
└──────────────┬───────────────┘
               │
               ▼
┌──────────────────────────────┐
│             MCU              │
│ HOME / READY / PRELOAD       │
│ RELEASE / RECOVER / INDEX    │
│ FAULT / SAFE                 │
└───────┬───────────────┬──────┘
        │               │
        │               └──────────► 供给索引执行器
        │
        ├──────────────────────────► 两轴指向机构
        │
        └──────────────────────────► 预载/边界/释放执行器
                                      │
                                      ▼
                        ┌────────────────────────┐
                        │ 机械脉冲核心             │
                        │ Stage 1                │
                        │      ↓                 │
                        │ Stage 2                │
                        │      ↓                 │
                        │ 柔性膜片                │
                        └──────────┬─────────────┘
                                   │
                          瞬态低能量空气位移
                                   │
                   ┌───────────────┴───────────────┐
                   ▼                               ▼
              Mode A                         Mode B
             纯空气模式                  超轻软载荷模块
                                                │
                                                ▼
                                        6–8 位旋转供给盘
```

---

# 5. 机械核心定义

## 5.1 Stage 1

功能：

- 接收低速位移输入；
- 储存弹性能量；
- 在达到结构临界状态时快速 snap-through。

Stage 1 不负责直接接触软载荷。

---
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

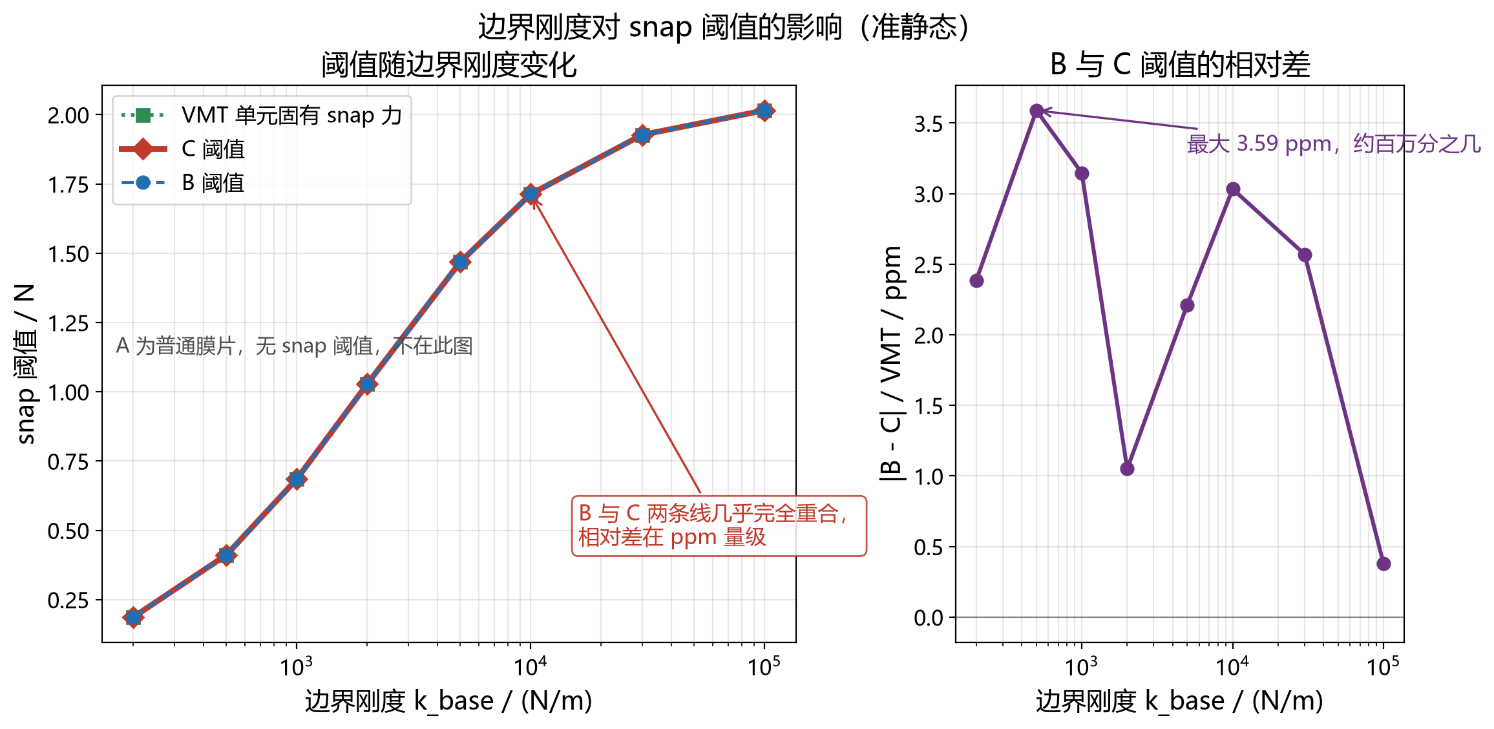
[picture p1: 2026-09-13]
09_PLOTS/fig03_boundary_threshold.png

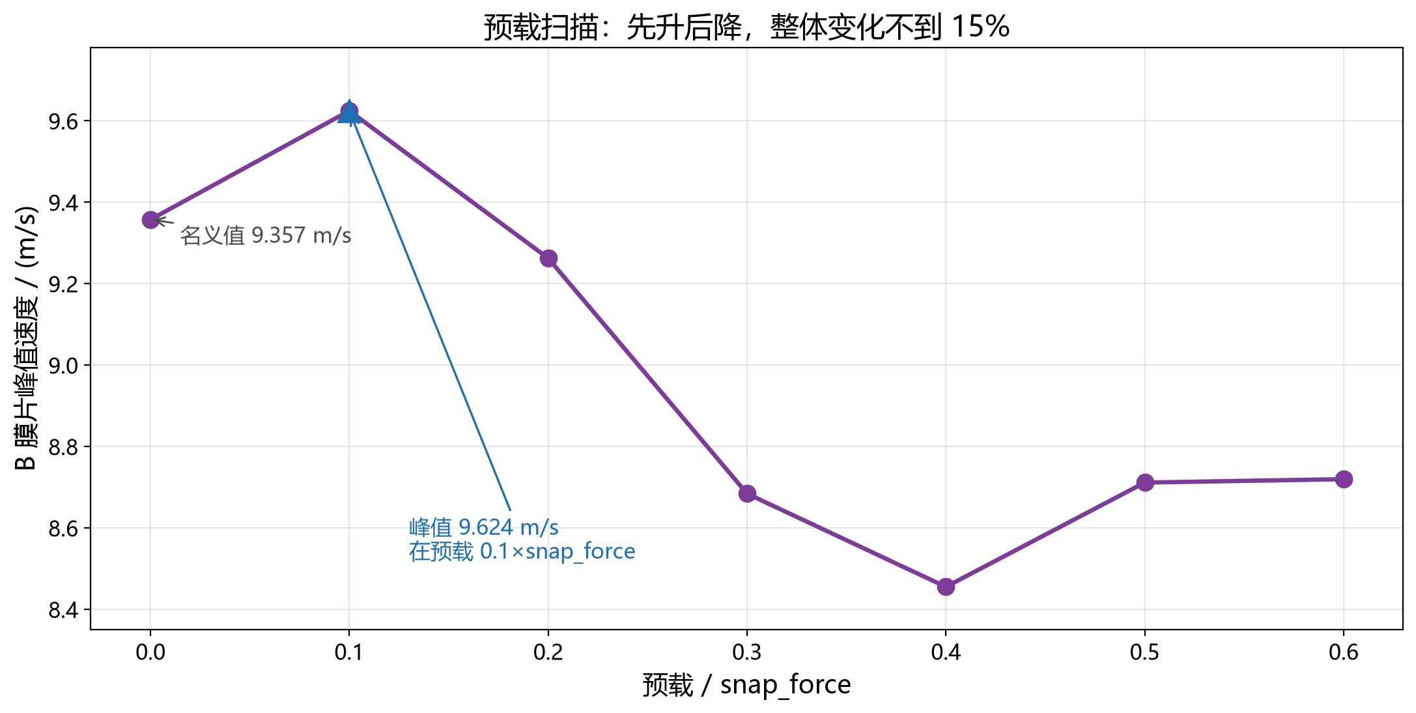
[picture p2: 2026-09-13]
09_PLOTS/fig07_sweep_preload.png

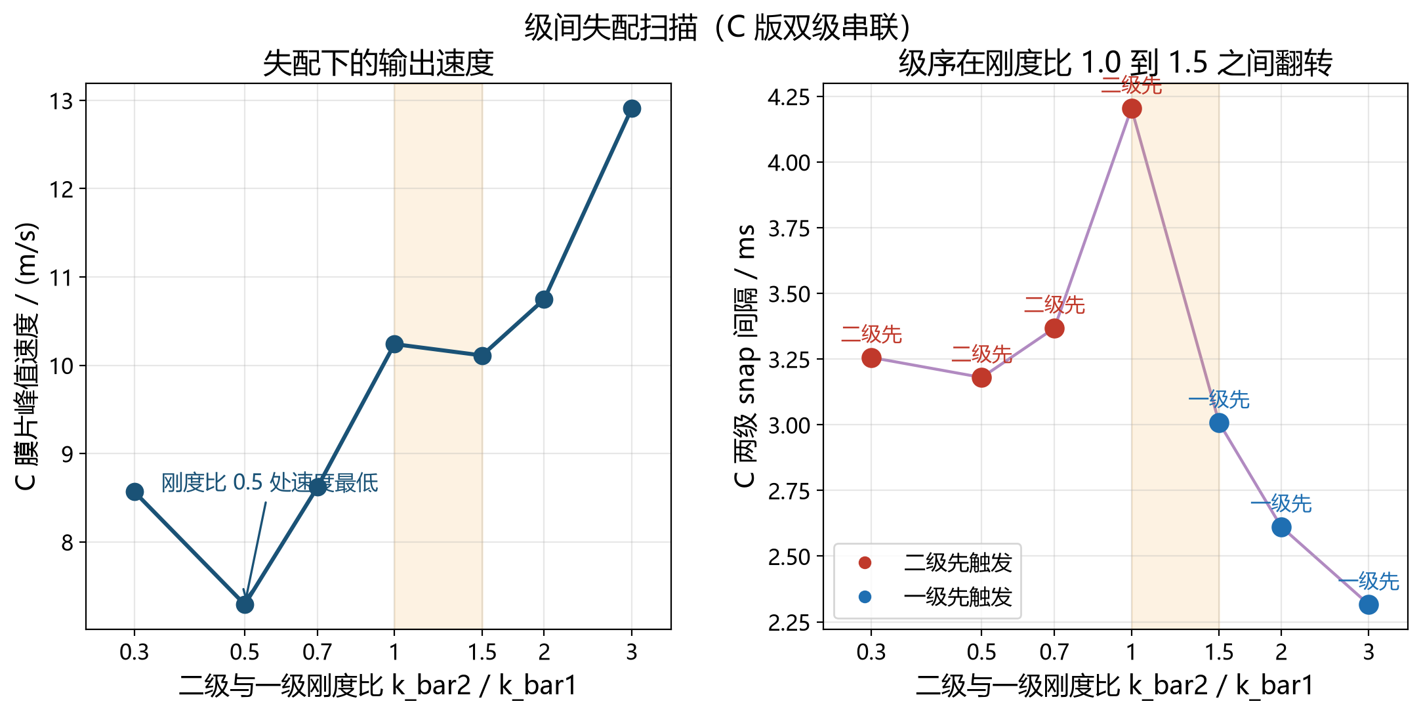
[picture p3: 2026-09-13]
09_PLOTS/fig04_sweep_mismatch.png

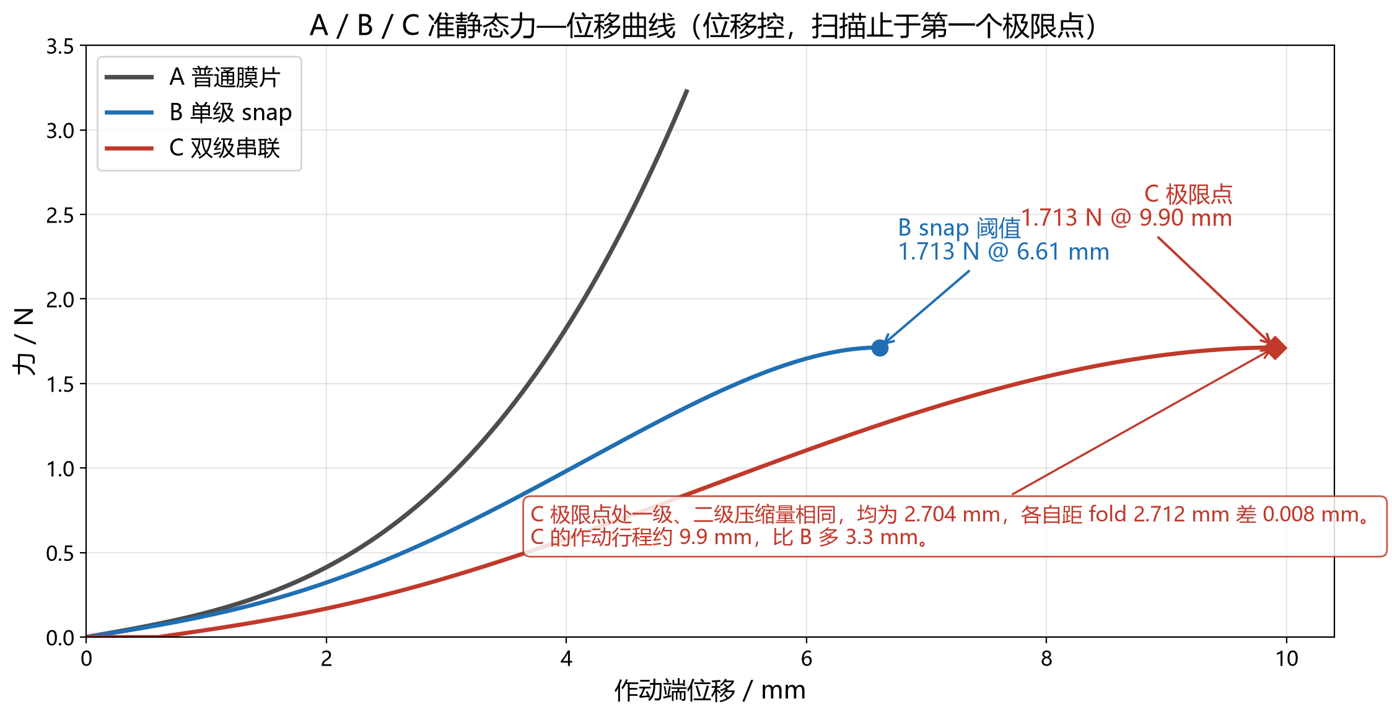
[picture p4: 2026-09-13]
09_PLOTS/fig01_force_displacement.png

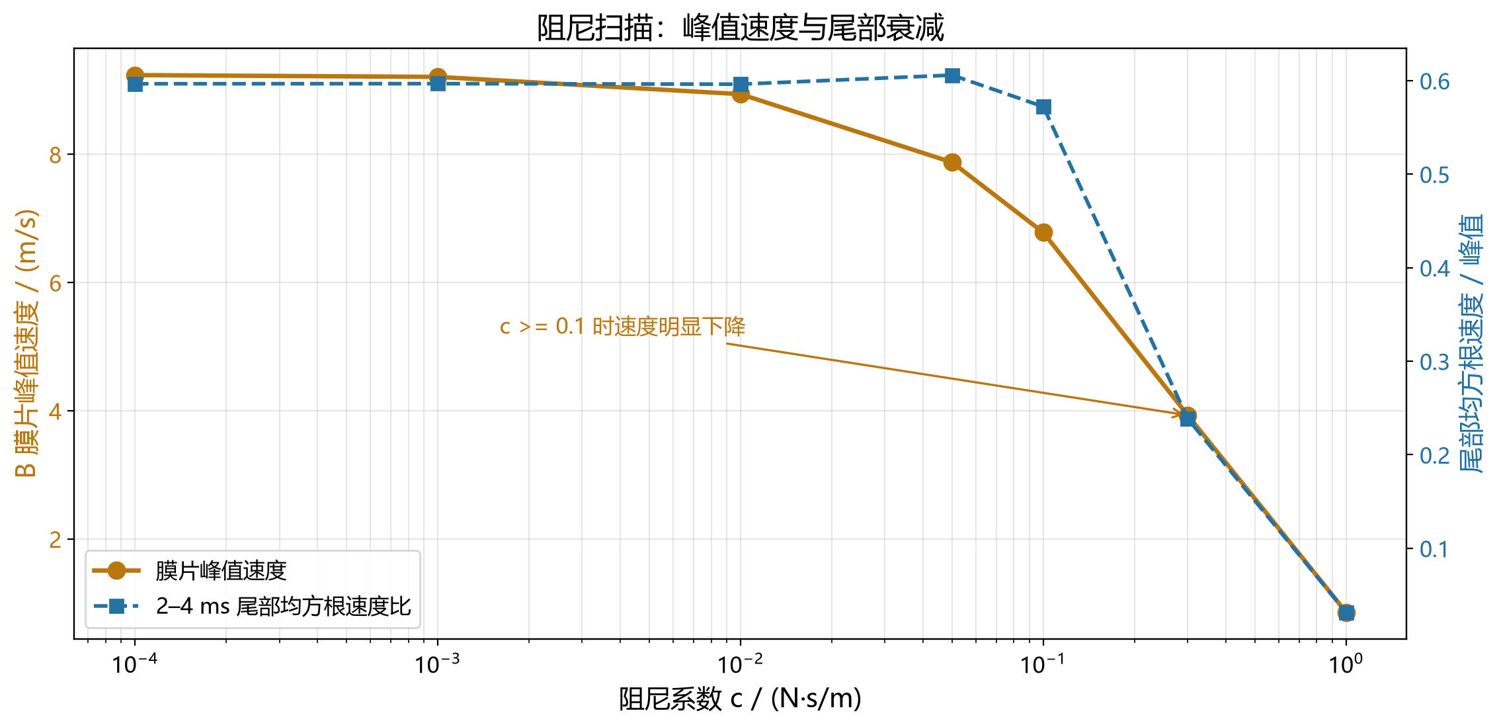
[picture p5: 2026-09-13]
09_PLOTS/fig06_sweep_damping.png

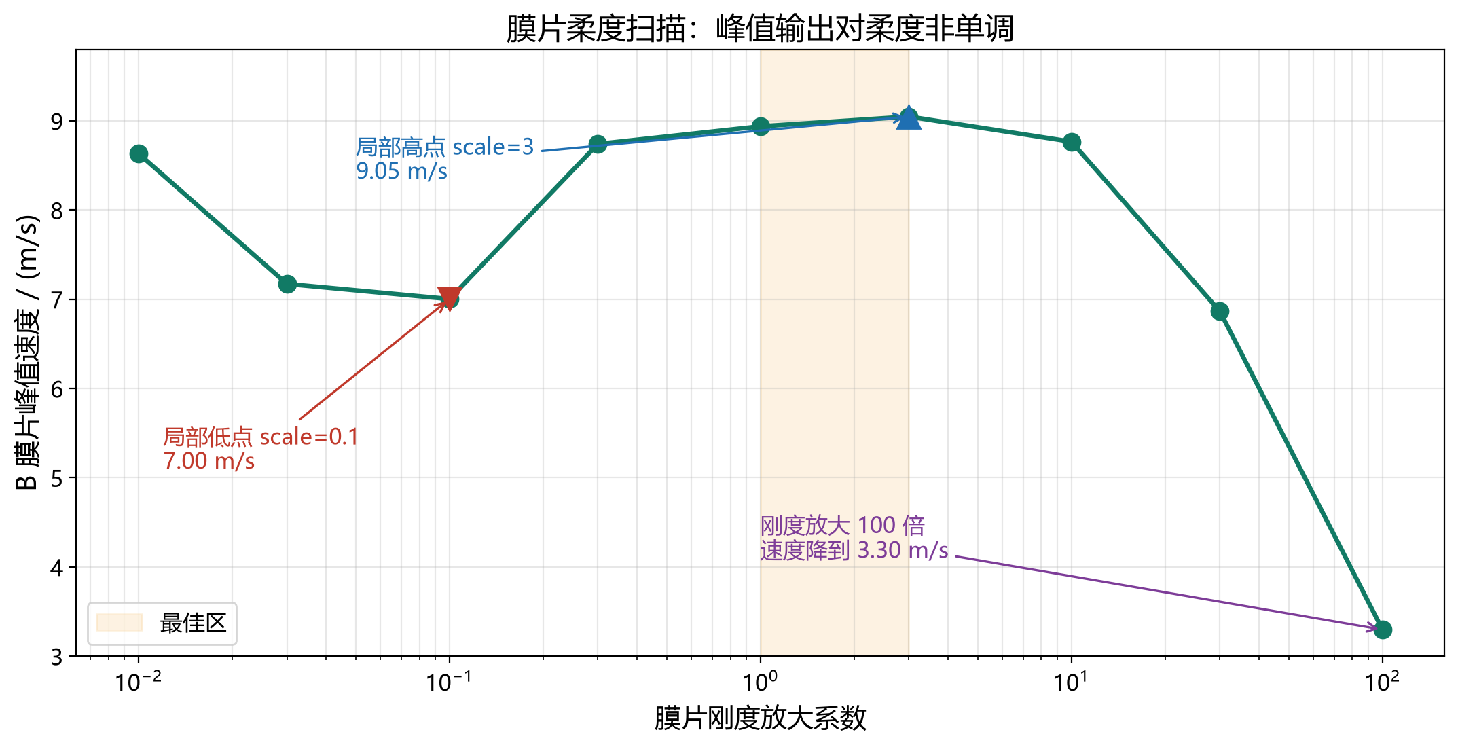
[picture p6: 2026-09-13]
09_PLOTS/fig05_sweep_membrane.png

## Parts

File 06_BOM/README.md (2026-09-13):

# 06_BOM

物料清单放这里，主文件是 `bom.csv`。规格书 §21 给的是设计预算，不是实时市场报价，单位是人民币。
表里没有逐项数量、单价、供应商、替代料这些字段，因为 §21 只给了分类成本区间，规格书未给的信息就不编造。
等实际询价后再决定要不要加这些列。

## 这份 BOM 是什么

它是设计阶段的预算口径，用来判断机械方案有没有超 ¥50，不是采购单。各列含义如下。

- `item`：项目名称。
- `category`：口径分组。取值有几类：`炮头机械架构`（计入 ¥50）、`不计入¥50-后台或外设`、`汇总`、`核算`、`预算规则`（规则与说明行不参与求和）。
- `target_cost_cny_min` / `target_cost_cny_max`：规格书 §21 给的目标成本区间。规格书未给成本的行留空。
- `counted_in_50`：这一行是否计入 §1.1 的 ¥50 炮头机械架构预算。机械件为 `yes`，后台外设为 `no`，规则与汇总行留空。
- `included_in_quote`：这一行是否出现在本次 ¥50 报价核算口径内。与 `counted_in_50` 一致，机械件 `yes`，后台外设 `no`。
- `note`：口径说明、默认决策或引用出处。

## 范围边界（§1.1）

计入 ¥50 的只有炮头机械架构本身。CSV 里 `counted_in_50=yes` 的 9 行就是全部：弹性片、膜片材料、轴/销/铜套、小轴承（如果确有必要）、小磁铁、O 型圈/密封件、M2/M3 紧固件、软质实验载荷、其他机械杂件。

不计入 ¥50 的按原清单完整列出，`counted_in_50=no`：MCU、主控板、传感器后台、云台舵机、云台电机、发射/蓄能所用外部执行电机或舵机、电源、PCB、线材、通信模块、3D 打印材料成本、CAD/仿真/实验仪器成本。这些行成本留空，标了「规格书未给」。

3D 打印材料不计入 ¥50。打印件只负责框架、支撑、限位、边界切换、模块定位，不能因为打印便宜就改机械方案。

## 核算结果

按 CSV 中 `counted_in_50=yes` 的 9 行求和：

- 下限合计 = 3+2+2+2+1+2+2+1+2 = **¥17**
- 上限合计 = 8+5+5+8+3+5+4+3+5 = **¥46**

§21 的目标总计为 ¥17–46，两边对上。推荐 ≤ ¥40，硬限制 < ¥50。上限 46 低于硬限制，但高于推荐值 40，所以按上限采购时要先按下面的顺序压。

## 超预算削减顺序（§21）

按顺序执行，前面能解决就不动后面的：

1. 先减非必要轴承。低载荷小角度优先铜套或打印导向。
2. 再减 CNC/金属定制件。改用打印件或标准件。
3. 再减多余装饰壳。
4. 最后减不必要传动级。

有四项不得删减：状态检测、防脱结构、必要密封、安全互锁。CSV 底部四行 `不可删减-*` 记录了这条约束。

## 更新时机

- 实际询价后：更新单价与供应商信息，历史价格留在 note 里并写询价日期。
- `03_CAD/` 出图后：按图纸核对件数与规格，确认没有多买或漏买。
- 结构冻结后：确认实际选型仍落在 ¥50 内，并把与设计预算的偏差记进 note。
- 整合成本核算以这份表为准。

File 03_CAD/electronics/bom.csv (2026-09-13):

位号 | 型号 | 数量 | 封装 | 作用
R1 | 10k | 1 | Resistor_SMD:R_0805_2012Metric | FIRE_INHIBIT_N 下拉，开路即否决
R2 | 10k | 1 | Resistor_SMD:R_0805_2012Metric | FIRE_INHIBIT_N 串联限流
R3 | 10k | 1 | Resistor_SMD:R_0805_2012Metric | EXTERNAL_ALLOW 下拉，开路即拒绝
R4 | 10k | 1 | Resistor_SMD:R_0805_2012Metric | EXTERNAL_ALLOW 串联限流
R5 | 10k | 1 | Resistor_SMD:R_0805_2012Metric | POCKET_ALIGNED 下拉，开路即禁止
R6 | 10k | 1 | Resistor_SMD:R_0805_2012Metric | POCKET_ALIGNED 串联限流
R7 | 10k | 1 | Resistor_SMD:R_0805_2012Metric | MECH_RECOVERED_RAW 上拉，断线被反相器判为未复位
R8 | 10k | 1 | Resistor_SMD:R_0805_2012Metric | ARM_CMD 下拉，开路不武装
R9 | 10k | 1 | Resistor_SMD:R_0805_2012Metric | DISARM_CMD 下拉
R10 | 10k | 1 | Resistor_SMD:R_0805_2012Metric | FAULT_CMD 下拉
R11 | 1k | 1 | Resistor_SMD:R_0805_2012Metric | MCU_RELEASE_CMD 串联限流
R12 | 10k | 1 | Resistor_SMD:R_0805_2012Metric | MCU_RELEASE_CMD 下拉，开路无请求
R13 | 1k | 1 | Resistor_SMD:R_0805_2012Metric | PRELOAD_CMD 串联限流
R14 | 10k | 1 | Resistor_SMD:R_0805_2012Metric | PRELOAD_CMD 下拉，开路不预载
R15 | 10k | 1 | Resistor_SMD:R_0805_2012Metric | PAN_HOME 开关下拉，开路视为未归零
R16 | 10k | 1 | Resistor_SMD:R_0805_2012Metric | TILT_HOME 开关下拉，开路视为未归零
R17 | 10k | 1 | Resistor_SMD:R_0805_2012Metric | MAG_HOME 开关下拉，开路视为未归零
R18 | 10k | 1 | Resistor_SMD:R_0805_2012Metric | MASTER_ENABLE_RAW 下拉，开路即失能
R19 | 33k | 1 | Resistor_SMD:R_0805_2012Metric | 单稳态定时电阻 R_EXT
R20 | 22k | 1 | Resistor_SMD:R_0805_2012Metric | 单稳态定时电阻 R_EXT
R21 | 100k | 1 | Resistor_SMD:R_0805_2012Metric | MOSFET 栅极下拉（开路即关断）
R22 | 100 | 1 | Resistor_SMD:R_0805_2012Metric | MOSFET 栅极串联电阻
R23 | 100k | 1 | Resistor_SMD:R_0805_2012Metric | MOSFET 栅极下拉（开路即关断）
R24 | 1k | 1 | Resistor_SMD:R_0805_2012Metric | 串联限流/指示灯限流
R25 | 1k | 1 | Resistor_SMD:R_0805_2012Metric | 串联限流/指示灯限流
R26 | 100k | 1 | Resistor_SMD:R_0805_2012Metric | POCKET_OR_MODE_A 下拉，两路都开路即禁止
R27 | 100k | 1 | Resistor_SMD:R_0805_2012Metric | MODE_A_RAW 下拉，装盘或断线即撤销旁路
R28 | 100k | 1 | Resistor_SMD:R_0805_2012Metric | POR 定时上拉
R29 | 10k | 1 | Resistor_SMD:R_0805_2012Metric | FAULT_SET_N 上拉
R30 | 10k | 1 | Resistor_SMD:R_0805_2012Metric | FAULT_RESET_N 上拉
R31 | 10k | 1 | Resistor_SMD:R_0805_2012Metric | ARM_RESET_N 上拉
R32 | 100k | 1 | Resistor_SMD:R_0805_2012Metric | HOME_AND 下拉，开路即无归零脉冲
C1 | 100n | 1 | Capacitor_SMD:C_0805_2012Metric | 滤波或去耦
C2 | 100n | 1 | Capacitor_SMD:C_0805_2012Metric | 滤波或去耦
C3 | 100n | 1 | Capacitor_SMD:C_0805_2012Metric | 滤波或去耦
C4 | 100n | 1 | Capacitor_SMD:C_0805_2012Metric | 滤波或去耦
C5 | 100n | 1 | Capacitor_SMD:C_0805_2012Metric | 滤波或去耦
C6 | 100n | 1 | Capacitor_SMD:C_0805_2012Metric | 滤波或去耦
C7 | 100n | 1 | Capacitor_SMD:C_0805_2012Metric | 滤波或去耦
C8 | 100n | 1 | Capacitor_SMD:C_0805_2012Metric | 滤波或去耦
C9 | 100n | 1 | Capacitor_SMD:C_0805_2012Metric | 滤波或去耦
C10 | 100n | 1 | Capacitor_SMD:C_0805_2012Metric | 滤波或去耦
C11 | 100n | 1 | Capacitor_SMD:C_0805_2012Metric | 滤波或去耦
C12 | 100n | 1 | Capacitor_SMD:C_0805_2012Metric | 滤波或去耦
C13 | 100n | 1 | Capacitor_SMD:C_0805_2012Metric | 滤波或去耦
C14 | 100n | 1 | Capacitor_SMD:C_0805_2012Metric | 滤波或去耦
C15 | 1u | 1 | Capacitor_SMD:C_0805_2012Metric | 单稳态定时电容 C_EXT
C16 | 1u | 1 | Capacitor_SMD:C_0805_2012Metric | 单稳态定时电容 C_EXT
C17 | 10u | 1 | Capacitor_SMD:C_1206_3216Metric | 逻辑轨储能
C18 | 100n | 1 | Capacitor_SMD:C_0805_2012Metric | 滤波或去耦
C19 | 100n | 1 | Capacitor_SMD:C_0805_2012Metric | 滤波或去耦
C20 | 100n | 1 | Capacitor_SMD:C_0805_2012Metric | 滤波或去耦
C21 | 100n | 1 | Capacitor_SMD:C_0805_2012Metric | 滤波或去耦
C22 | 100n | 1 | Capacitor_SMD:C_0805_2012Metric | 滤波或去耦
C23 | 100n | 1 | Capacitor_SMD:C_0805_2012Metric | 滤波或去耦
D1 | SS34 | 1 | Diode_SMD:D_SMA | 肖特基：释放电磁铁续流
D7 | BAT54W | 1 | Diode_SMD:D_SOD-123 | 肖特基：模式A旁路与对齐信号的二极管或
D8 | BAT54W | 1 | Diode_SMD:D_SOD-123 | 肖特基：模式A旁路与对齐信号的二极管或
D11 | 1N4148W | 1 | Diode_SMD:D_SOD-123 | 小信号：上电复位脉冲到两个锁存器
D12 | 1N4148W | 1 | Diode_SMD:D_SOD-123 | 小信号：上电复位脉冲到两个锁存器
D13 | SMBJ16A | 1 | Diode_SMD:D_SMB | TVS：执行轨瞬态钳位
D14 | SS14 | 1 | Diode_SMD:D_SMA | 肖特基：逻辑轨输入防反
D9 | GATE_OK | 1 | LED_SMD:LED_0805_2012Metric | LED：释放门 Q2 使能指示
D10 | FAULT | 1 | LED_SMD:LED_0805_2012Metric | LED：故障锁存指示
F1 | MF-MSMF050 | 1 | Fuse:Fuse_1206_3216Metric | 自恢复保险丝：逻辑轨
F2 | MF-MSMF200 | 1 | Fuse:Fuse_1812_4532Metric | 自恢复保险丝：执行轨
F3 | MF-MSMF110 | 1 | Fuse:Fuse_1206_3216Metric | 自恢复保险丝：预载轨
M1 | AO3400A | 1 | Package_TO_SOT_SMD:SOT-23 | 低边N沟道MOSFET：释放/预载执行器回流开关
M2 | AO3400A | 1 | Package_TO_SOT_SMD:SOT-23 | 低边N沟道MOSFET：释放/预载执行器回流开关
JP1 | MODE_A_EN | 1 | Jumper:SolderJumper-2_P1.3mm_Open_Pad1.0x1.5mm | 焊接跳线：模式A旁路使能，默认闭合
U1 | 74HC21 | 1 | Package_SO:SOIC-14_3.9x8.7mm_P1.27mm | 双4输入与门：构成 Q1/Q2 与门树
U2 | 74HC123 | 1 | Package_SO:SOIC-16_3.9x9.9mm_P1.27mm | 双可重触发单稳态：钳释放脉冲宽度、产生归零复位脉冲
U3 | 74HC74 | 1 | Package_SO:SOIC-14_3.9x8.7mm_P1.27mm | 双D触发器：故障锁存器 U3A、武装锁存器 U3B
U4 | 74HC11 | 1 | Package_SO:SOIC-14_3.9x8.7mm_P1.27mm | 三3输入与门：HOME 与、武装时钟门、取消武装逻辑
U5 | 74HC14 | 1 | Package_SO:SOIC-14_3.9x8.7mm_P1.27mm | 六施密特反相器：MECH_RECOVERED 反相、故障/脉冲/命令取反、整形
U6 | 74HC08 | 1 | Package_SO:SOIC-14_3.9x8.7mm_P1.27mm | 四2输入与门：主使能与预载的故障门控
J1 | PWR_IN | 1 | Connector_PinHeader_2.54mm:PinHeader_1x04_P2.54mm_Vertical | 连接器：PWR_IN
J2 | ACT_OUT | 1 | Connector_PinHeader_2.54mm:PinHeader_1x03_P2.54mm_Vertical | 连接器：ACT_OUT
J3 | SAFETY_IN | 1 | Connector_PinHeader_2.54mm:PinHeader_1x20_P2.54mm_Vertical | 连接器：SAFETY_IN
J4 | PRELOAD_OUT | 1 | Connector_PinHeader_2.54mm:PinHeader_1x03_P2.54mm_Vertical | 连接器：PRELOAD_OUT
J5 | HOME | 1 | Connector_PinHeader_2.54mm:PinHeader_1x04_P2.54mm_Vertical | 连接器：HOME
J6 | MODE_MAG | 1 | Connector_PinHeader_2.54mm:PinHeader_1x03_P2.54mm_Vertical | 连接器：MODE_MAG
J7 | ESTOP | 1 | Connector_PinHeader_2.54mm:PinHeader_1x06_P2.54mm_Vertical | 连接器：ESTOP
J8 | KEY | 1 | Connector_PinHeader_2.54mm:PinHeader_1x03_P2.54mm_Vertical | 连接器：KEY
J9 | STATUS | 1 | Connector_PinHeader_2.54mm:PinHeader_1x08_P2.54mm_Vertical | 连接器：STATUS
TP1 | FIRE_INHIBIT_N | 1 | TestPoint:TestPoint_Pad_D1.5mm | 测试点：FIRE_INHIBIT_N
TP2 | EXTERNAL_ALLOW | 1 | TestPoint:TestPoint_Pad_D1.5mm | 测试点：EXTERNAL_ALLOW
TP3 | MECH_RECOVERED_N | 1 | TestPoint:TestPoint_Pad_D1.5mm | 测试点：MECH_RECOVERED_N
TP4 | POCKET_OR_MODE_A | 1 | TestPoint:TestPoint_Pad_D1.5mm | 测试点：POCKET_OR_MODE_A
TP5 | Q1_OUT | 1 | TestPoint:TestPoint_Pad_D1.5mm | 测试点：Q1_OUT
TP6 | Q2_OUT | 1 | TestPoint:TestPoint_Pad_D1.5mm | 测试点：Q2_OUT
TP7 | RELEASE_PULSE | 1 | TestPoint:TestPoint_Pad_D1.5mm | 测试点：RELEASE_PULSE
TP8 | FAULT_LATCH | 1 | TestPoint:TestPoint_Pad_D1.5mm | 测试点：FAULT_LATCH
TP9 | HOME_AND | 1 | TestPoint:TestPoint_Pad_D1.5mm | 测试点：HOME_AND
TP10 | MASTER_ENABLE_RAW | 1 | TestPoint:TestPoint_Pad_D1.5mm | 测试点：MASTER_ENABLE_RAW

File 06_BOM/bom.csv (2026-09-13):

item | category | target_cost_cny_min | target_cost_cny_max | counted_in_50 | included_in_quote | note
弹性片 | 炮头机械架构 | 3 | 8 | yes | yes | 301/304 弹簧不锈钢薄片或 PET 弹性片；先 PET 做几何验证再弹簧钢做寿命版
膜片材料 | 炮头机械架构 | 2 | 5 | yes | yes | 薄硅胶或 TPU 或 PET 膜；至少并行比较一种弹性体膜和一种聚酯膜
轴/销/铜套 | 炮头机械架构 | 2 | 5 | yes | yes | 低载荷小角度优先铜套或打印导向
小轴承（如果确有必要） | 炮头机械架构 | 2 | 8 | yes | yes | 只有确有必要才加；超预算时第一个被减
小磁铁 | 炮头机械架构 | 1 | 3 | yes | yes | 用于零位或状态检测磁路
O 型圈/密封件 | 炮头机械架构 | 2 | 5 | yes | yes | 必要密封不可删
M2/M3 紧固件 | 炮头机械架构 | 2 | 4 | yes | yes | 标准件
软质实验载荷 | 炮头机械架构 | 1 | 3 | yes | yes | EVA 或 EPP 超轻圆片；早期可用毛毡或纸片
其他机械杂件 | 炮头机械架构 | 2 | 5 | yes | yes | 含防脱结构等零散件
小计-炮头机械架构 | 汇总 | 17 | 46 |  |  | 9 项下限求和为 17；上限求和为 46；与 §21 目标总计一致
核算结论 | 核算 |  |  |  |  | 目标总计 ¥17–46；推荐 ≤ ¥40；硬限制 < ¥50；本表上限 46 低于硬限制但高于推荐值 40；按上限采购时需按削减顺序压到 40 以内
MCU | 不计入¥50-后台或外设 |  |  | no | no | 规格书未给成本；不计入 ¥50；不得为省 MCU 破坏机械方案
主控板 | 不计入¥50-后台或外设 |  |  | no | no | 规格书未给成本；不计入 ¥50
传感器后台 | 不计入¥50-后台或外设 |  |  | no | no | 规格书未给成本；不计入 ¥50
云台舵机 | 不计入¥50-后台或外设 |  |  | no | no | 规格书未给成本；不计入 ¥50
云台电机 | 不计入¥50-后台或外设 |  |  | no | no | 规格书未给成本；不计入 ¥50
发射/蓄能所用外部执行电机或舵机 | 不计入¥50-后台或外设 |  |  | no | no | 规格书未给成本；不计入 ¥50
电源 | 不计入¥50-后台或外设 |  |  | no | no | 规格书未给成本；不计入 ¥50
PCB | 不计入¥50-后台或外设 |  |  | no | no | 规格书未给成本；不计入 ¥50
线材 | 不计入¥50-后台或外设 |  |  | no | no | 规格书未给成本；不计入 ¥50
通信模块 | 不计入¥50-后台或外设 |  |  | no | no | 规格书未给成本；不计入 ¥50
3D 打印材料成本 | 不计入¥50-后台或外设 |  |  | no | no | 规格书未给成本；不计入 ¥50；打印件只做框架/支撑/限位/边界切换
CAD/仿真/实验仪器成本 | 不计入¥50-后台或外设 |  |  | no | no | 规格书未给成本；不计入 ¥50
超预算削减顺序-第1步 | 预算规则 |  |  |  |  | 先减非必要轴承；铜套或打印导向能替代就替代
超预算削减顺序-第2步 | 预算规则 |  |  |  |  | 再减 CNC/金属定制件；改用打印件或标准件
超预算削减顺序-第3步 | 预算规则 |  |  |  |  | 再减多余装饰壳
超预算削减顺序-第4步 | 预算规则 |  |  |  |  | 最后减不必要传动级
不可删减-状态检测 | 预算规则 |  |  |  |  | 状态检测相关零件与传感接口；超预算也不得删减
不可删减-防脱结构 | 预算规则 |  |  |  |  | 防止载荷意外脱出的结构；超预算也不得删减
不可删减-必要密封 | 预算规则 |  |  |  |  | 膜片与气路相关密封；超预算也不得删减
不可删减-安全互锁 | 预算规则 |  |  |  |  | §11 机械安全互锁相关结构；超预算也不得删减

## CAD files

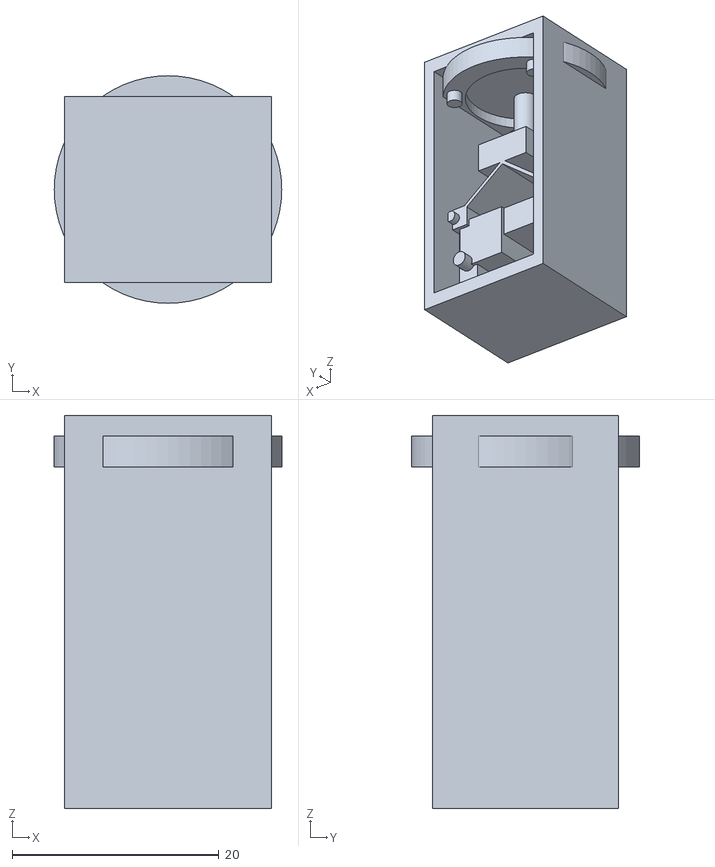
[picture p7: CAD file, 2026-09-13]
03_CAD/MST-01B/exports/MST-01B_assembly.stl
22.0 x 22.0 x 38.0

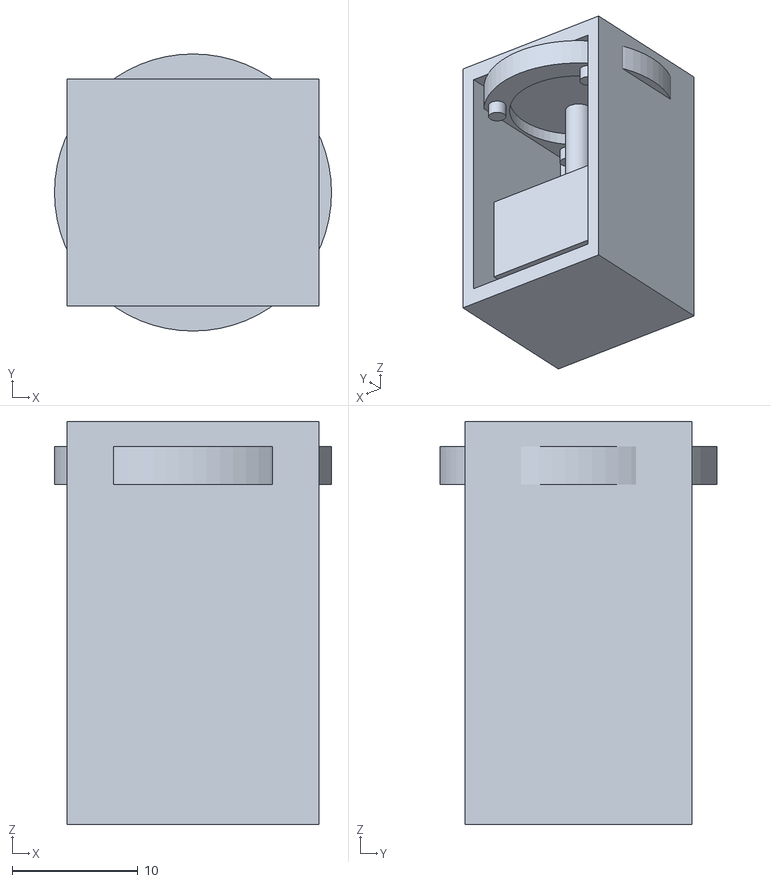
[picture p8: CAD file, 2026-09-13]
03_CAD/MST-01A/exports/MST-01A_assembly.stl
22.0 x 22.0 x 32.0

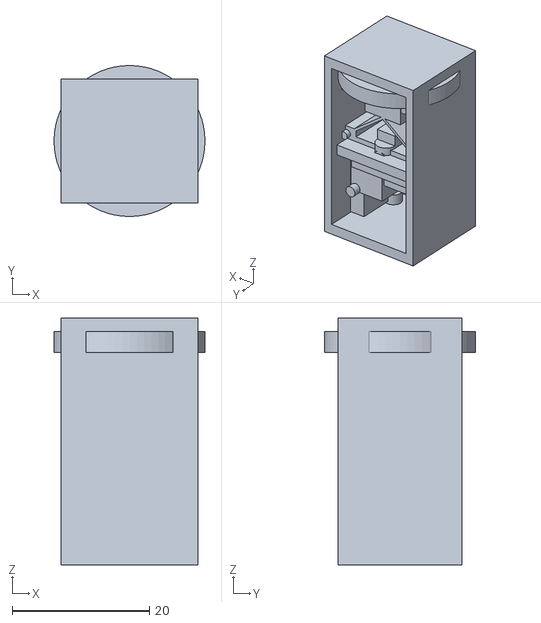
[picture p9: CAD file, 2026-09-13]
03_CAD/MST-01D/exports/MST-01D_single_locked_assembly.stl
22.0 x 22.0 x 36.0

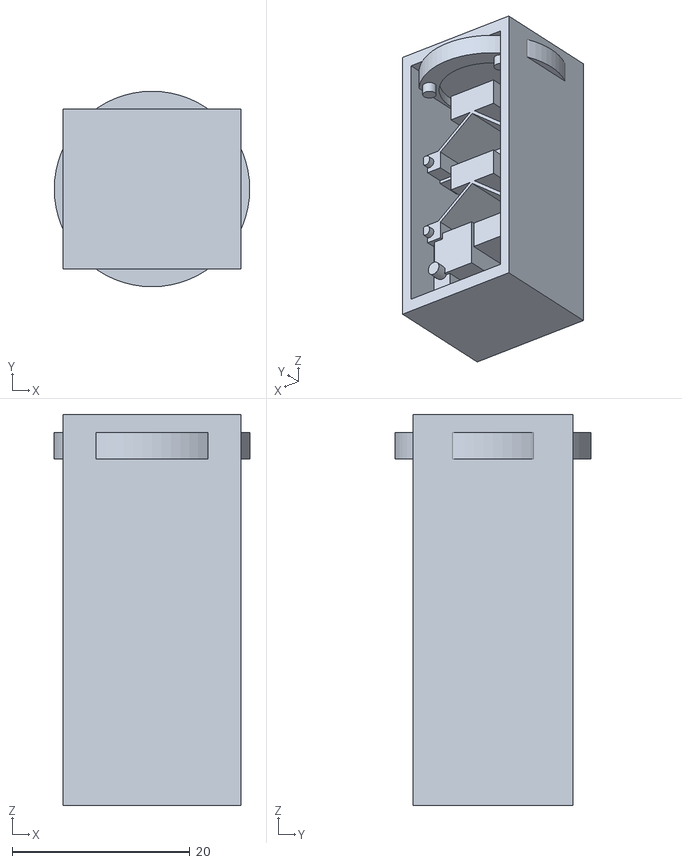
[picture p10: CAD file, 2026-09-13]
03_CAD/MST-01C/exports/MST-01C_assembly.stl
22.0 x 22.0 x 44.0

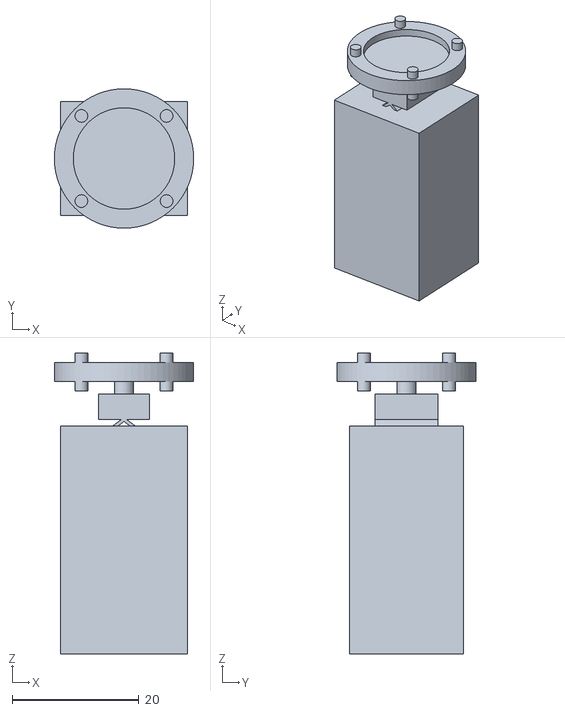
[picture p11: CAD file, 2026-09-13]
03_CAD/MST-01D/exports/MST-01D_dual_locked_assembly.stl
22.0 x 22.0 x 47.5

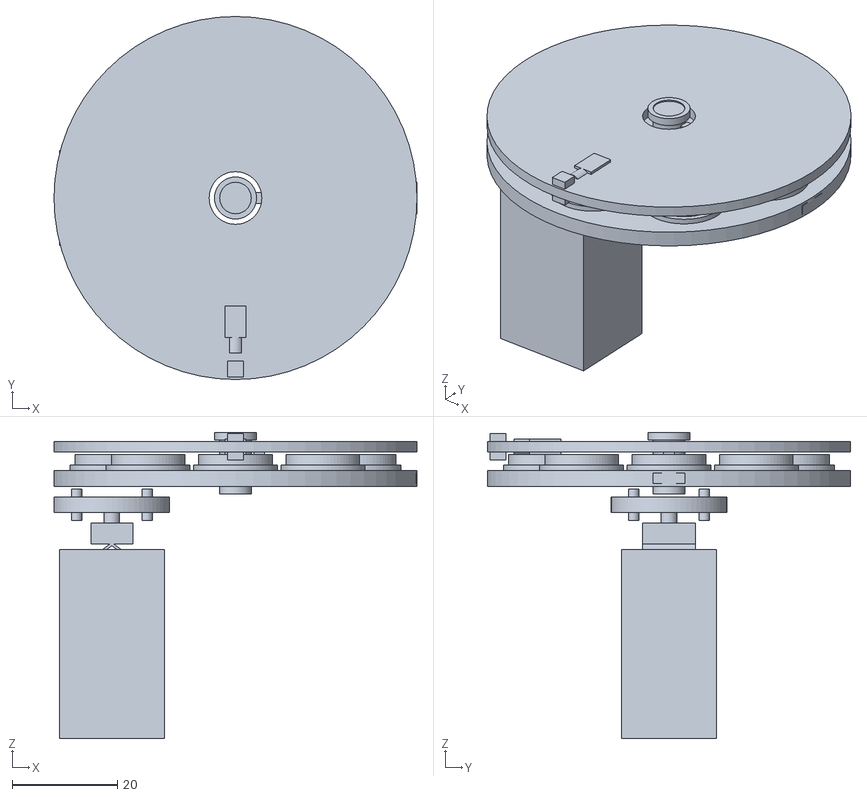
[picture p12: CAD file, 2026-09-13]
03_CAD/MST-01E/exports/MST-01E_dual_8pos_assembly.stl
69.0 x 69.0 x 58.2

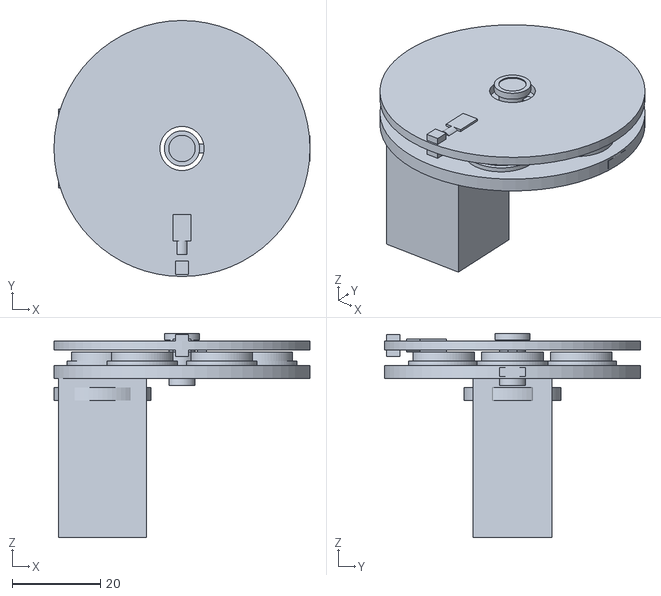
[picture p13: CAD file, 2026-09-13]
03_CAD/MST-01E/exports/MST-01E_single_6pos_assembly.stl
58.0 x 58.0 x 46.2

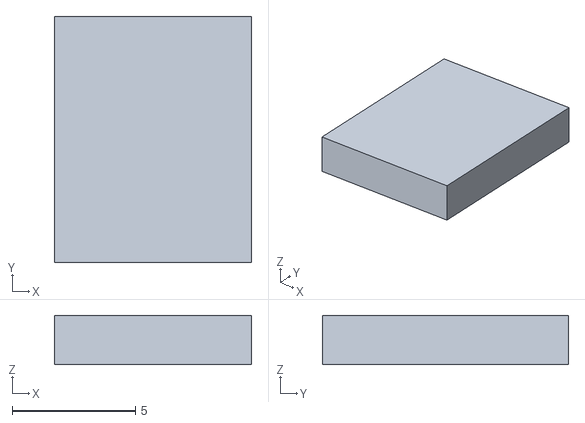
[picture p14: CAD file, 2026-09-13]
03_CAD/MST-01D/exports/PRELOAD_pusher.stl
8.00 x 10.0 x 2.00

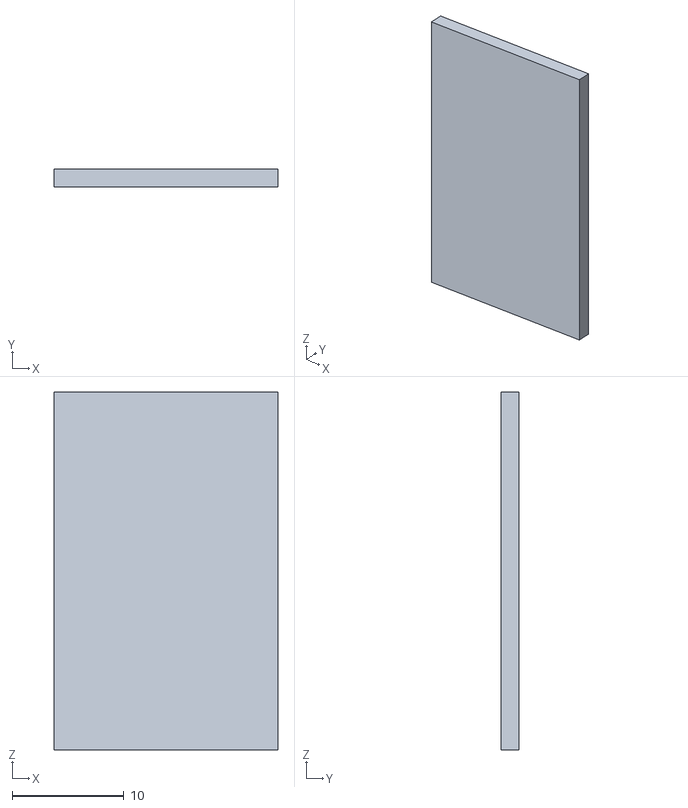
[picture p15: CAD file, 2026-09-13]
03_CAD/MST-01E/exports/FRAME_base_plate.stl
20.0 x 1.60 x 32.0

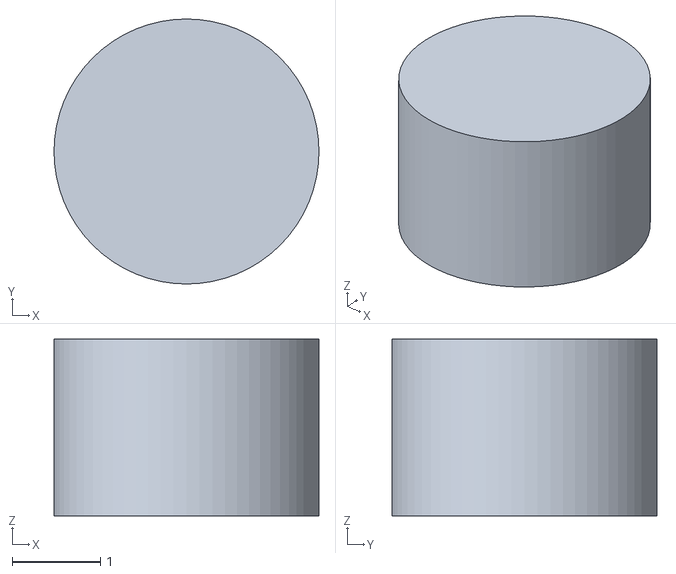
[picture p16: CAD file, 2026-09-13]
03_CAD/MST-01D/exports/OUTPUT_rod.stl
3.00 x 3.00 x 2.00

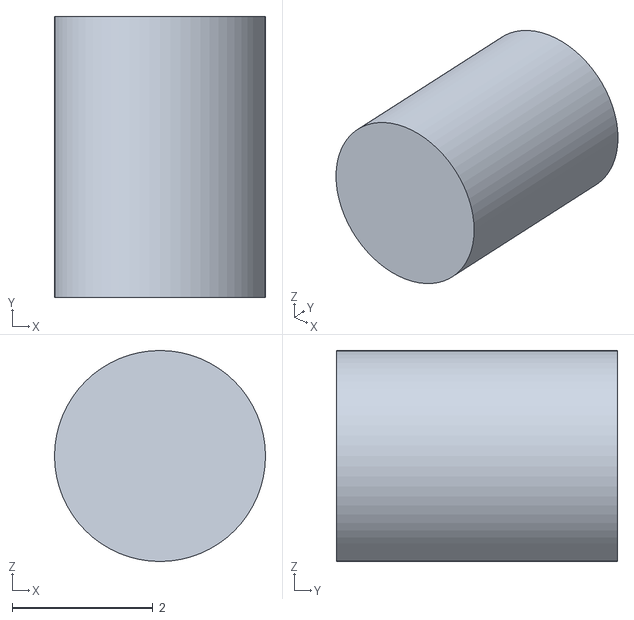
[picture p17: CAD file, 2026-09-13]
03_CAD/MST-01E/exports/BOUNDARY_detent_plunger.stl
3.00 x 4.00 x 3.00

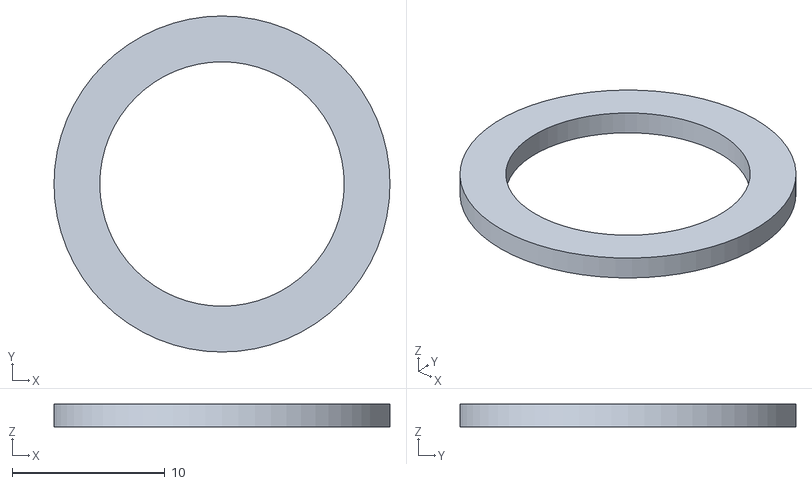
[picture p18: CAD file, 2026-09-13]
03_CAD/MST-01D/exports/DIAPHRAGM_ring_front.stl
22.0 x 22.0 x 1.50

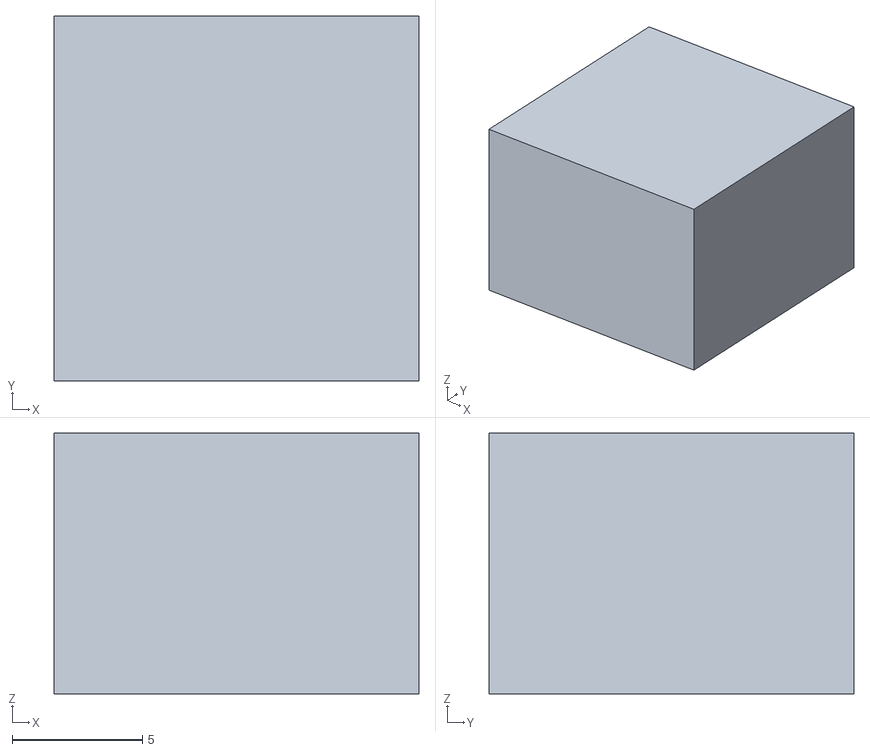
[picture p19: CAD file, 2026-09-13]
03_CAD/MST-01A/exports/ACTUATOR_body.stl
14.0 x 14.0 x 10.0

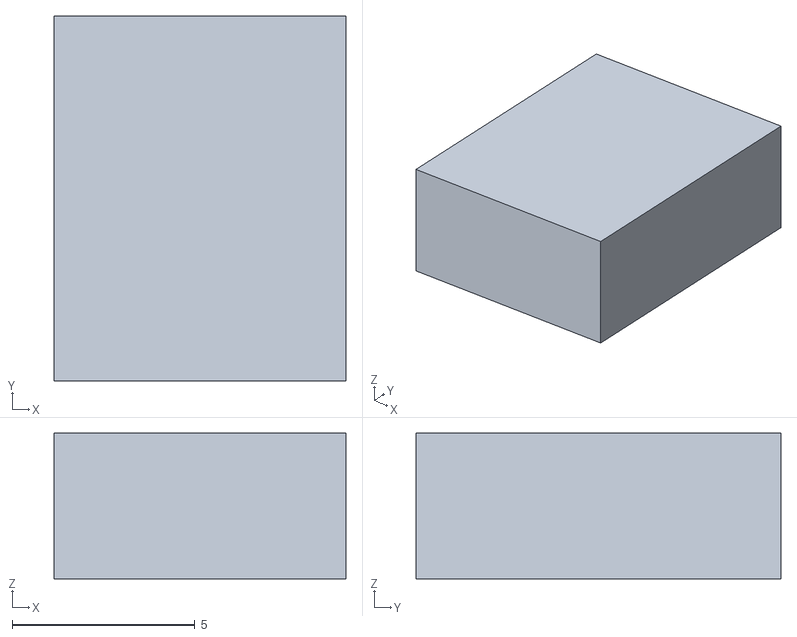
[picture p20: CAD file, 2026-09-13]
03_CAD/MST-01D/exports/STAGE_1_apex_slider.stl
8.00 x 10.0 x 4.00

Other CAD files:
03_CAD/MST-01E/exports/STAGE_1_base_clamp_posx.stl
03_CAD/MST-01D/exports/DIAPHRAGM_disc.stl
03_CAD/MST-01E/exports/MAGAZINE_axle.stl
03_CAD/MST-01A/exports/ACTUATOR_pushrod.stl
03_CAD/MST-01A/exports/DIAPHRAGM_disc.stl
03_CAD/MST-01A/exports/DIAPHRAGM_ring_front.stl
03_CAD/MST-01A/exports/DIAPHRAGM_ring_rear.stl
03_CAD/MST-01A/exports/DIAPHRAGM_screw_0.stl
03_CAD/MST-01A/exports/DIAPHRAGM_screw_1.stl
03_CAD/MST-01A/exports/DIAPHRAGM_screw_2.stl
03_CAD/MST-01A/exports/DIAPHRAGM_screw_3.stl
03_CAD/MST-01A/exports/FRAME_base_plate.stl
03_CAD/MST-01A/exports/FRAME_front_rim.stl
03_CAD/MST-01A/exports/FRAME_wall_negx.stl
03_CAD/MST-01A/exports/FRAME_wall_posx.stl
03_CAD/MST-01B/exports/DIAPHRAGM_disc.stl
03_CAD/MST-01B/exports/DIAPHRAGM_ring_front.stl
03_CAD/MST-01B/exports/DIAPHRAGM_ring_rear.stl
03_CAD/MST-01B/exports/DIAPHRAGM_screw_0.stl
03_CAD/MST-01B/exports/DIAPHRAGM_screw_1.stl
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

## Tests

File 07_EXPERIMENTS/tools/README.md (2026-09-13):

# 工具链（07_EXPERIMENTS/tools）

PC 端工具链，在开发机上跑，不烧进固件。作用是把固件、算法参考实现和真实舵盘接起来：
标定相机、标定轴角、采遥测、评精度。

依赖见 requirements.txt：numpy、opencv-python、pyserial、pytest。

```
python -m pip install -r 07_EXPERIMENTS/tools/requirements.txt
```

算法数学不在这些脚本里实现，全部 import `05_FIRMWARE/algo_reference/src/aim`。`common.py` 把该目录
挂进 `sys.path`，之后 `from aim.geometry import ...` 直接可用。要改数学去改
algo_reference，改这里没用。

## 典型顺序

1. `calibrate_intrinsics.py` 棋盘格标内参，得到 fx/fy/cx/cy 和畸变系数
2. `calibrate_axis.py` 打点解出像素角度到舵盘角的仿射
3. `capture_telemetry.py` 串口采固件遥测，MST 记录行与 DIAG 帧轨迹一起收
4. `analyze_telemetry.py` 出机制指标与指向/时序验收指标

## 遥测两条线

固件同时输出两条遥测线，前缀不同，用途不同，解析互不影响。

`MST,` 是规格书 §19 的实验记录，每发一条，共 17 个字段：时间戳、实验号、原型与机构版本、
模式、边界与预载状态、膜片与载荷编号、循环计数、两级事件计数、机构恢复、工位、索引到位、
故障码、操作备注。机制类指标用它算。

`DIAG,` 是每控制拍的帧轨迹，由 `AIM_VERBOSE_TELEMETRY` 开关控制，开发期打开、发布期关闭。
共 16 个字段，顺序如下：

```text
DIAG,timestamp_ms,loop_us,obs_valid,obs_dropped,px,py,confidence,
     pan_deg,tilt_deg,pan_target_deg,tilt_target_deg,
     err_pan_deg,err_tilt_deg,err_deg,aim_state,has_feedback
```

| 字段 | 单位 | 含义 |
|---|---|---|
| `timestamp_ms` | ms | 本拍 `millis()` |
| `loop_us` | us | 本拍控制环耗时，不含遥测打印 |
| `obs_valid` | 无 | 本拍是否有新鲜有效观测，1/0 |
| `obs_dropped` | 无 | 本拍尝试取帧但失败，1/0 |
| `px` `py` | px | 目标质心像素坐标 |
| `confidence` | 无 | 质心置信度 0..1 |
| `pan_deg` `tilt_deg` | 度 | 两轴当前角 |
| `pan_target_deg` `tilt_target_deg` | 度 | 两轴本拍目标角 |
| `err_pan_deg` `err_tilt_deg` | 度 | 目标质心相对光轴的角偏差分量 |
| `err_deg` | 度 | 角偏差合成量，静态指向 RMSE 按它算 |
| `aim_state` | 无 | `AimState` 整数值，3=TRACKING，4=LOCKED |
| `has_feedback` | 无 | 两轴任一有位置反馈 |

`obs_valid=0` 时 `px`/`py`/`confidence`/`err_*` 都写 0，统计时按 `obs_valid=1` 过滤。

发布固件（`AIM_VERBOSE_TELEMETRY=0`）不输出 `DIAG,` 行，只保留 `MST,` 低频心跳；这时三项
验收指标无法计算，`analyze_telemetry.py` 会给出提示并照常输出机制类指标。

## 脚本

### calibrate_intrinsics.py

棋盘格内参标定，用 OpenCV。检测一个目录下所有图片的角点，标出内参和畸变系数，输出
JSON 存档和一段 C 宏。

```
python calibrate_intrinsics.py calib_images --cols 9 --rows 6 --square 25
```

`--cols`/`--rows` 是内角点数，常见板子 9x6 或 7x5。`--square` 是方格边长（mm）。

注意：`05_FIRMWARE/include/config.h` 目前没有相机内参宏，固件的内参存在 NVS 里
（见 `05_FIRMWARE/src/calibration/calibration.h`）。脚本输出的 C 片段按 config.h 现有的
`CAM_` 命名习惯给出（`CAM_FX` 等），想把它当编译期兜底值就自行加进 config.h 的 VISION
段，或者抄进 NVS 初始值。

缺 opencv-python 时会打印安装提示后退出，不抛 traceback。

### calibrate_axis.py

轴角标定。输入一张对应点表，每行是目标像素和该点在画面中央时的舵盘角：

```
px,py,pan_deg,tilt_deg
120.0,80.0,3.2450,-1.8720
...
```

流程是像素先经 `pixel_to_angles` 转 bearing/elevation（度），再用
`solve_affine_angle_to_pan_tilt` 最小二乘解 2x3 仿射 A，满足
`q = A · (bearing, elevation, 1)`，输出 pan/tilt。随机留出一部分点（固定 seed）只做评估，
用它们的 RMSE 按推导文档第 10 节给评价。

```
python calibrate_axis.py points.csv --holdout 0.3 --seed 0
```

内参优先用 `--intrinsics-json`（calibrate_intrinsics.py 的输出），否则读 config.h 的内参宏，
都没有就用 config.h 图像尺寸生成占位内参。也可以用 `--fx --fy --cx --cy` 等直接覆盖。

脚本还会算标定点的包围盒占比，全挤在画面中央会警告：外推区的误差会被放大。输出 JSON
存档和一段 C 数组，字段名对应 `CalibrationData::affine`。

### capture_telemetry.py

串口采集固件遥测，`MST,` 与 `DIAG,` 两条线都收，原样写进同一个 CSV。两条线靠行前缀区分，
文件开头有两行以 `#` 起的表头注释。这样一次采集就能同时拿到机构记录和帧轨迹，不用开两个
串口或跑两遍。

```
python capture_telemetry.py --port COM5 --duration 20 --out run1.csv
python capture_telemetry.py --lines 3000 --out run2.csv
python capture_telemetry.py --list
```

`--duration` 和 `--lines` 二选一，都不给按 10 秒采；`--lines` 数的是两条线的合计数据行。
采完打印两线各自行数、实测采样率、MST 的预载/边界/故障分布，以及 DIAG 的 AimState 分布。
串口打不开会列出当前可用串口；中途断开会保留已采数据并提示重插。缺 pyserial 时打印安装
提示后退出。发布固件没有 DIAG 行，脚本会提示这一点。

### analyze_telemetry.py

读采集到的 CSV，按前缀分流后出两类指标：

机制类（数据源 `MST,`）：

- 运行信息：实验号、原型级别、机构变体
- 采样间隔：相邻两行 `timestamp` 差值的均值、最大、95 分位
- 机构恢复率：`mechanism_recovered` 为 1 的比例，目标 100%
- 索引到位率：`magazine_index_ok` 为 1 的比例，目标 100%
- 故障：非零 `fault_code` 的行数与分布，带软/硬分级
- 循环计数跨度、级间事件累计、工位覆盖、预载/边界/模式分布

指向与验收类（数据源 `DIAG,`，对照 `02_REQUIREMENTS/方案设计.md` §11.1）：

- 静态指向 RMSE：`obs_valid=1` 且 `aim_state=LOCKED` 的样本，按 `err_deg` 算均方根，目标 ≤ 0.5°
- 控制周期：`loop_us` 换算成毫秒，给均值与最大值，目标 ≤ 5 ms
- 锁定建立时间：从首个有效观测到首次进入 LOCKED，目标 ≤ 500 ms

```
python analyze_telemetry.py run1.csv
python analyze_telemetry.py run1.csv --json report.json
```

输入只有 `MST,` 没有 `DIAG,` 时，脚本不报错，机制类报告照常输出，验收指标区给出
「未发现 DIAG, 行」的提示，不打印空表。

### make_sample_axis_points.py

生成 `sample_axis_points.csv`。样例用默认 QVGA 内参和一组虚拟仿射反算得到，带 0.03 度
噪声，只为让 calibrate_axis.py 能端到端跑通，不代表任何真实设备。真实标定自己打点。

```
python make_sample_axis_points.py
```

## 测试

```
cd 07_EXPERIMENTS/tools
python -m pytest -q
```

只测不依赖硬件和 OpenCV 的部分：遥测行解析、config.h 宏解析、精度统计、仿射解算。

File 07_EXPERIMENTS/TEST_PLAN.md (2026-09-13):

# MST-01 实验计划（TEST_PLAN.md）

本文件对应主规格 §13 的原型序列、§14 的不可跳级、§16 的第一阶段流程、§17 的循环寿命、
§18 的供给盘独立实验，以及 §33 交付项。

执行纪律固定为 A → B → C → D → E，每一级达到通过标准才进入下一级（REQ-108）。任何一级不通过，
按 §30 对应条目处理，不得绕过继续。

规格书没有给出量化的通过标准，只给了判定方向（如 B1 看是否明显更快、重复、振铃过大）。
下文里的通过标准是可执行口径，属于本文件新增定义，评审确认后生效；判据中的百分比在拿到 A1 基线数据后
可以收紧或放宽，调整要记进本文件变更记录。

数据文件放在 `07_EXPERIMENTS/` 下对应的 A/B/C/D/E 目录。命名沿用 §16 的 `A1_force.csv` 风格，
同一测试的曲线、视频、笔记用同一前缀。所有记录同时满足 §19 的数据字段要求。

---

## 0. 通用约定

### 0.1 测试台与测量链

- 力：力传感器，采 force-displacement，采样率要能分辨 snap 事件。
- 位移：膜片位移传感器或高速视频跟踪，采 membrane displacement-time。
- 压力：低量程压力传感器，采 low-range pressure-time。量程在 A1 前确定并记录。
- 事件：STAGE1_STATE、STAGE2_STATE 直连 GPIO 中断，捕获 snap 事件时刻。磁钢靶的动力学扰动按 RSK-13 对照。
- 视频：高速视频记录机构动作，用于事件可分辨性与顺序核对。
- 环境：温度、装夹方式、操作者记进 notes。

### 0.2 每次动作的记录字段

输入变量按 §15.1，输出变量按 §15.2。

- 记录变量（输入）：mechanism version、boundary state、preload state、membrane material、
  membrane mounting、stage combination、cycle count。
- 测量变量（输出）：force-displacement curve、Stage 1 event time、Stage 2 event time、
  membrane displacement-time、low-range pressure-time、recovery time、repeatability、
  indexing success、fatigue drift。
- 结构化字段按 §19 的 timestamp 到 operator_note 全列出，fault_code 用枚举值（REQ-125）。

### 0.3 重复性口径

本文的「相对标准差」指同一条件下多次有效动作的样本标准差除以均值。除特别说明，默认每个条件
至少 10 次有效动作。

---

## A 级：MST-01A 普通膜片基线

### 进入条件

项目起点，没有上一级结论。前置是 MST-01A 的 CAD、测试台测量链、第一期的云台与状态机联调平台可用。
Mode A 纯空气模式（REQ-100）。

### 测试项

Test A1 普通膜片（§16）。低速执行器直接推动膜片，无 snap-through。

### 测量变量

force-displacement、membrane displacement-time、low-range pressure-time、recovery time、repeatability。

### 记录变量

mechanism version（A）、boundary state（默认 fixed）、preload state、membrane material、
membrane mounting、stage combination（single-passive）、cycle count。

### 数据文件名

```text
07_EXPERIMENTS/A/A1_force.csv
07_EXPERIMENTS/A/A1_displacement.csv
07_EXPERIMENTS/A/A1_pressure.csv
07_EXPERIMENTS/A/A1_video.*
07_EXPERIMENTS/A/A1_notes.md
```

### 通过标准

- 三条曲线都能稳定采到，无丢帧、无饱和，采样率足以分辨推入过程。
- 同一条件下膜片峰值位移与压力峰值的相对标准差不超过 10%，作为后续对照的重复性基线。
- force-displacement 与位移、压力时间曲线在复装膜片后仍可复现。
- 至少比较一种弹性体膜与一种聚酯膜（REQ-081），两种材料的数据都在。

### 不通过时的行动

属于测量链或装夹问题，修传感器、装夹、膜片后重测。不涉及 STOP 条件，不进 B 级。

---

## B 级：MST-01B 单级 snap

### 进入条件

A1 通过，基线数据与重复性口径确认，MST-01B CAD 与 STAGE1_STATE 采集通道可用（架构 §8）。
必须回放 A1 数据作为对照。

### 测试项

Test B1 单级 snap（§16）。一个失稳单元，与 A1 比较。

### 测量变量

force-displacement、Stage 1 event time、membrane displacement-time、low-range pressure-time、
recovery time、repeatability。

### 记录变量

同 A1，stage combination 改为 single-snap；boundary state 默认 fixed；增加弹性元件材料与厚度。

### 数据文件名

```text
07_EXPERIMENTS/B/B1_force.csv
07_EXPERIMENTS/B/B1_displacement.csv
07_EXPERIMENTS/B/B1_pressure.csv
07_EXPERIMENTS/B/B1_events.csv
07_EXPERIMENTS/B/B1_video.*
07_EXPERIMENTS/B/B1_notes.md
```

### 通过标准

判定方向来自 §16：膜片响应是否明显更快、是否可重复、是否产生过大振铃。可执行口径：

- 相对 A1，膜片到达峰值位移的时间中位数改善不低于 20%，或压力上升时间明显缩短。
- Stage 1 snap 事件能被 STAGE1_STATE 稳定捕获，事件时刻的相对标准差不超过 10%。
- 振铃不过大：主峰之后的振荡衰减到主峰 20% 以内的时间，不超过主峰上升时间的三倍。口径可调。
- 重复性不差于 A1，峰值位移与压力峰值相对标准差不超过 10%。

#### 模型先验预测（来自 `04_SIMULATION/`，纯软件，非实测）

以下预测用在实验里证伪或证实，不替代上面的通过标准。模型假设：`k_bar` 未标定、膜片线弹性且无粘弹滞后、
忽略摩擦与重力气压反作用与流体耦合、作动器理想化、一维对称质量集中。

- 模型给出单级相对普通膜片的膜片峰值速度为 8.939 对 0.469 m/s，约 19.1 倍；输入功 19.963 对 2.615 mJ。
- B1 实测若复现这个量级的优势，STOP-01 不触发，可继续 C 级，模型此条被证实。
- 这条预测也是 C1 的对照基准：模型认为单级已经拿到大部分收益（19.1 倍），双级只再多 18%。若 B1 复现，
  STOP-02 里「双级机构的复杂度与收益不匹配」这一面的先验成立，最终判定仍要等 C1。
- B1 实测若与模型相反，单级对普通膜片无可测优势，先触发 STOP-01。此时最可能失真的模型假设是
  `k_bar` 未实测、膜片粘弹滞后未建模、流体耦合缺失，应先核查这三项，再判断是模型偏差还是单级本身无价值。

### 不通过时的行动

**STOP-01**：单级相对普通膜片没有可测优势，停止双级研究（REQ-142）。按架构 §6.8 落成构建期机构
变体常量加研究门控标志，进 FAULT 之外的研究降级，结果记录到 10_FAILURE_ANALYSIS。也顺带检查
MECH_RECOVERED 判定可靠性（架构 §9.3、§6.11 末的 ARMED 卸载能力）。

---

## C 级：MST-01C 双级串联 snap

### 进入条件

B1 通过，单级相对普通膜片的优势可测且可重复。MST-01C CAD 与 STAGE2_STATE 采集通道可用。
这一级才开始判断 sequential snap 是否真有价值（§13）。

### 测试项

Test C1 双级 snap（§16）。两个失稳单元串联。

### 测量变量

force-displacement、Stage 1 event time、Stage 2 event time、inter-stage delay、
membrane displacement-time、low-range pressure-time、recovery time、repeatability。

### 记录变量

同 B1，stage combination 改为 dual-snap；记录两级弹性元件的几何与厚度、级间 gap。

### 数据文件名

```text
07_EXPERIMENTS/C/C1_force.csv
07_EXPERIMENTS/C/C1_displacement.csv
07_EXPERIMENTS/C/C1_pressure.csv
07_EXPERIMENTS/C/C1_events.csv
07_EXPERIMENTS/C/C1_video.*
07_EXPERIMENTS/C/C1_notes.md
```

### 通过标准

判定方向来自 §16：两个事件是否可分辨、顺序是否固定、是否偶发同时 snap、是否比 B 更有价值。
可执行口径：

- 两个 snap 事件在不少于 90% 的有效动作中可分辨，且顺序固定。
- 偶发同时 snap 的比例低于 5%。
- inter-stage delay 的相对标准差不超过 15%。
- 相对 B1，至少一项有工程价值的改善（脉冲峰值、上升时间、重复性之一），且寿命相关指标不显著下降。

#### 模型先验预测（来自 `04_SIMULATION/`，纯软件，非实测）

以下预测用在实验里证伪或证实，不替代上面的通过标准。模型假设同 B1：`k_bar` 未标定、膜片线弹性且
无粘弹滞后、忽略摩擦与重力气压反作用与流体耦合、作动器理想化、一维对称质量集中。

- 模型给出 C 相对 B 的膜片峰值速度为 10.573 对 8.939 m/s，只有约 18% 的增益；输入功从 19.963 升到
  37.623 mJ，接近翻倍。
- 模型准静态下两级各距 fold 只有 0.008 mm，几乎同时跳变；瞬态下级序不稳定，刚度失配 k_bar2/k_bar1
  到 1.5 倍即从 (1,0) 翻为 (0,1)，级间间隔在 2.32 到 7.20 ms 之间漂移。
- C1 实测若复现上述倾向，命中的是 STOP-02 里「更不稳定」这一分句，并支持「双级机构的复杂度与收益不匹配」。
  但「响应没有区别」不成立，模型自己就给出 18% 差异；「寿命下降严重」要等 §17 的 100/500/1000 阶梯。
  三个分句要一起看，不能只凭级序不稳就宣布命中 STOP-02。
- C1 实测若与模型相反，双级相对单级确有实质增益（明显超过 18%，且级序稳定），则模型在当前假设下失效。
  最可能失真的假设是 `k_bar` 未实测（边界刚度与等效杆刚度都依赖它）、膜片粘弹滞后未建模、流体耦合缺失。
  这三项要先通过标定和带气腔与压力的实验补齐，再重做解释。

### 不通过时的行动

**STOP-02**：双级比单级明显更差（更不稳定、响应无区别、寿命下降严重），回退单级（REQ-143）。
按架构 §6.8 走构建期回退，记录到 10_FAILURE_ANALYSIS。C 级通过后才允许进 D。

---

## D 级：MST-01D 可切换边界研究版

### 进入条件

C1 通过，双级相对单级有可测价值。MST-01D CAD 与 BOUNDARY_CMD 通道可用，边界状态可记录。
D 版定位为科研变量验证，不等于专利点（REQ-110）。

### 测试项

Test D1 边界变化（§16）。至少两个状态：BOUNDARY_0、BOUNDARY_1。

### 测量变量

force-displacement、stage order、inter-stage delay、membrane response、repeatability、fatigue drift。

### 记录变量

同 C1，boundary state 在 BOUNDARY_0 与 BOUNDARY_1 间切换；记录边界切换方式（locked/released）与预载状态。

### 数据文件名

```text
07_EXPERIMENTS/D/D1_B0_force.csv
07_EXPERIMENTS/D/D1_B0_displacement.csv
07_EXPERIMENTS/D/D1_B0_pressure.csv
07_EXPERIMENTS/D/D1_B1_force.csv
07_EXPERIMENTS/D/D1_B1_displacement.csv
07_EXPERIMENTS/D/D1_B1_pressure.csv
07_EXPERIMENTS/D/D1_events.csv
07_EXPERIMENTS/D/D1_video.*
07_EXPERIMENTS/D/D1_notes.md
```

### 通过标准

判定方向来自 §16 与 STOP-03：边界切换要有稳定可复现的输出差异。可执行口径：

- BOUNDARY_0 与 BOUNDARY_1 在 force-displacement、stage order、inter-stage delay、membrane response
  中至少两项存在可区分差异，建议以均值差超过合并标准差为判据。
- 两个状态各自的重复性仍满足 A1 口径。
- 跨天重测时差异方向和量级一致，即差异可复现。

### 不通过时的行动

**STOP-03**：boundary switching 没有稳定可复现的输出差异，D 版不进入论文主线（REQ-144）。
记录并关闭边界研究分支（架构 §6.8），核心机械照常推进。D 通过才允许多花精力在 E 之前继续边界研究。

---

## E 级：MST-01E 自动供给完整版

§16 只定义到 D1，E 级没有编号测试项。下文的 E1 是本文件派生的集成测试，判定门槛引用 §9.2 的工作逻辑
与 §18 的供给盘验收。E 级的前置是 M1 已通过。

### 进入条件

D1 通过（或边界分支按 STOP-03 关闭但核心机械通过）。M1 供给盘独立验收通过。MST-01E 的 MAG_* 通道、
Mode B 载荷与旋转盘装配完成。

### 测试项

- Test M1 供给盘独立实验（§18）作为进入前置。
- Test E1 完整发射周期集成（派生）：READY → 动作 → RECOVER → 确认复位 → INDEX → INDEX_OK → READY（§9.2）。

### 测量变量

recovery time、indexing success、membrane displacement-time、low-range pressure-time、repeatability。

### 记录变量

增加 magazine_position、magazine_index_ok、payload_id；mode 取 Mode B；记录每发载荷位与是否人工干预。

### 数据文件名

```text
07_EXPERIMENTS/E/E1_cycle.csv
07_EXPERIMENTS/E/E1_displacement.csv
07_EXPERIMENTS/E/E1_pressure.csv
07_EXPERIMENTS/E/E1_video.*
07_EXPERIMENTS/E/E1_notes.md
```

### 通过标准

- M1 已通过（人工复位不超过 1 次）。
- 完整周期连续不少于 30 发，无人工干预；INDEX_OK 失败不超过 1 次。
- 每发都能确认机械核心复位（MECH_RECOVERED 为真）后才开始索引。
- Mode B 出膛一致：视频核对无卡弹、双片、错位。
- 每发按 §19 写全字段。

### 不通过时的行动

卡料相关失败按 **STOP-04** 处理，先修供给，不与炮头集成（REQ-145）。其他失败按现象定位到具体一级，
回退到 C 或 D 重测。集成期若机构在储能态被顶死，升级 FAULT 并保持硬件断开（架构 §6.8）。

---

## 循环寿命测试（§17）

### 适用范围

在 B/C 中证明有价值的失稳机构上做，包括对应的膜片与弹性元件。测试对象是机械核心，不带供给盘。

### 阶梯与检查项

按 100、500、1000 次阶梯，每级结束检查：snap threshold 漂移、裂纹、塑性变形、膜片松弛、螺丝松动、
传感误判、恢复失败（§17、REQ-119）。

### 数据文件名

```text
07_EXPERIMENTS/C/LIFE_100.csv
07_EXPERIMENTS/C/LIFE_500.csv
07_EXPERIMENTS/C/LIFE_1000.csv
07_EXPERIMENTS/C/LIFE_notes.md
```

路径按被测机构所在级调整，单级放 B，双级放 C。

### 通过标准

- snap threshold 漂移不超过 10%。阈值口径在 B1 数据后确定。
- 无可见裂纹，无明显塑性变形。
- 膜片松弛导致的峰值位移衰减不超过 10%。
- 紧固件无松动，传感无误判，恢复失败 0 次。
- 每级的数据与 A1 重复性口径可比。

### 不通过时的行动

100 次已经明显漂移则不得进入集成版（§17、REQ-120）。换弹簧钢弹性件或改几何后重测；
连续两轮仍漂移则重评失稳方案。寿命结论记录到 10_FAILURE_ANALYSIS。

---

## 供给盘独立验收（§18）

### 前置

供给模块脱离炮头单独运行（REQ-121）。M1 在 E 级集成之前必须完成。

### 测试项

Test M1 连续 50 次索引（§18）。

### 测量与记录变量

```text
index_command
index_detected
jam
double_feed
misalignment
manual_reset
```

### 数据文件名

```text
07_EXPERIMENTS/E/M1_index.csv
07_EXPERIMENTS/E/M1_video.*
07_EXPERIMENTS/E/M1_notes.md
```

### 通过标准

- 50 次索引中人工复位不超过 1 次（REQ-123）。
- 出现 jam、double_feed、misalignment 时系统能按架构 §6.8 自动重试或安全停止，且不损伤机构。
- 每次索引都能读到 MAG_INDEX_OK，错位检测有效（载荷对齐参与释放门控，架构 §6.5 H3）。

### 不通过时的行动

**STOP-04**：50 次人工复位超过 1 次，先修供给，不与炮头集成。修完重跑 M1，通过后才做 E1。

---

## STOP 条件与实验通过标准对照

| STOP | 性质 | 对应实验 | 不通过时的动作 |
|---|---|---|---|
| STOP-01 | 实验结论 | B1 | 停止双级研究，研究降级，记录到 10_FAILURE_ANALYSIS |
| STOP-02 | 实验结论 | C1 | 回退单级，构建期机构变体回退，记录到 10_FAILURE_ANALYSIS |
| STOP-03 | 实验结论 | D1 | D 版不进入论文主线，记录并关闭边界研究分支 |
| STOP-04 | 运行期条件 | M1、E1 | 进软故障，单次 INDEX 重试；超门槛先修供给，不与炮头集成 |
| STOP-05 | 设计期预算 | BOM 校验 | 按 §21 顺序砍件，不得删状态检测、防脱、密封、互锁 |

STOP-05 不在实验通过标准里，它由设计评审的 BOM 校验门槛承担（架构 §6.8），
但每次出图后要按 `06_BOM/bom.csv` 核对。

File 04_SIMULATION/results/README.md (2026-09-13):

# results

三个 study 运行后会在这里产出 CSV，装了 matplotlib 时还会产出 PNG。

- `quasi_static.py`：`A_force_displacement.csv`、`B_force_displacement.csv`、
  `C_force_displacement.csv`、`boundary_sensitivity.csv`。
- `transient.py`：`transient_A.csv`、`transient_B.csv`、`transient_C.csv`、
  `transient_summary.csv`、`transient_velocity.png`。
- `parameter_study.py`：`sweep_boundary.csv`、`sweep_preload.csv`、
  `sweep_mismatch.csv`、`sweep_membrane.csv`、`sweep_damping.csv`。

CSV 一律是 UTF-8、逗号分隔、首行表头，长度单位 m，时间 s，力 N，质量 kg。
同名文件会被覆盖，重新跑 study 即刷新。这些是模型输出，不是实测数据；与实验
对照前不要直接引用绝对值。

快速重跑：

```bash
python studies/quasi_static.py
python studies/transient.py
python studies/parameter_study.py
python -m pytest -q
```

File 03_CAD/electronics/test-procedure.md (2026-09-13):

# MST-01 释放门控板 板级验证步骤

本文件对应统一架构方案 §6.11 第一条给出的验证方式：搭一块只有释放链和与门的小板，逐条
故意断开输入、故意让 MCU 输出常高，确认释放无动作。步骤按“可照做”写，每条给出预期结果
与不合格时的处置。

这套步骤只测硬件门控本身，不测状态机。软件状态机的验证另在固件侧做。

## 0. 仪器与准备

- 可调直流电源两台：一台供逻辑轨 3.3V，一台供执行轨（先按执行器铭牌取，未定型前先用
  与执行器同压的小功率假负载，例如同压灯泡或功率电阻，不要直接上真电磁铁做破坏性试验）。
- 万用表、示波器（至少两通道，带单次触发）、若干跳线与杜邦线。
- 一块已验证空板的释放门控板，元件按 `bom.csv` 装齐。
- 一个可两边操作的开关模拟器或一条可插拔跳线，用来模拟三处 HOME 与供给盘触点。
- 一个假负载网络替代电磁铁，串一只电流采样电阻，方便看通断。

安全注意：

- 执行轨的电压与能量按真实上限准备，急停回路必须先接好再上电。
- 通电时手不要碰执行器输出端子。释放动作虽然只有几十毫秒，电流不小。
- 每换一次接线，先断执行轨再动线，确认无误后重新上电。

约定：所有“给释放脉冲”的操作都指在满足其余条件时，给 `J3` 的 `MCU_RELEASE_CMD` 一个
上升沿（用信号源或手动跳一下 3.3V 再断开）。测栅极与漏极时先接好示波器探头。

## 1. 上电与静态默认

### T1 上电默认禁止

- 操作：只接 `+3V3`、`GND` 与执行轨，`J3` 到 `J9` 的所有信号线都不接。上电，测 `TP6`
  （`Q2_OUT`）、`M1` 栅极、执行器两端电压。
- 预期：`Q2_OUT` 为低，`M1` 栅极为低，执行器无电流。`TP8`（`FAULT_LATCH`）为低，
  `TP9`（`HOME_AND`）为低。
- 不合格处置：若执行器有电流，先查 `M1` 是否损坏、`R21` 是否漏装、`V_ACT_SW` 是否在
  上电瞬间就有电。在排除前不得继续后面的测试。

### T2 主使能关闭

- 操作：把 `FIRE_INHIBIT_N`、`EXTERNAL_ALLOW`、`MECH_RECOVERED_RAW`、`POCKET_ALIGNED`
  人为置到允许侧（`MECH_RECOVERED_RAW` 短到 `GND`，其余短到 `+3V3`），供给盘触点闭合，
  武装锁存人为置位（见 T20 的方法），但 `MASTER_ENABLE_RAW` 保持断开。给一次释放脉冲。
- 预期：`Q2_OUT` 保持低，执行器无电流。
- 不合格处置：查 `U6A` 与 `U1` 第 13 脚到第 8 脚的连接，确认 `MASTER_ENABLE_GATED` 确实
  跟随 `MASTER_ENABLE_RAW`。

### T3 逻辑轨断电

- 操作：在执行轨有电、其余条件人为满足的情况下，断掉 `+3V3`。
- 预期：`Q2_OUT` 随逻辑轨掉电变低，执行器无电流；`FAULT_LATCH` 在重新上电后为低。
- 不合格处置：查 `U1`、`U6` 的供电去耦和 `R18` 下拉。

## 2. 输入单项断开

每条都保留其余条件在允许侧，只动被测这一路。测量点是 `TP5`（`Q1_OUT`）、`TP6`。
用一次释放脉冲确认执行器是否动作。

### T4 FIRE_INHIBIT_N 断开

- 操作：断开 `J3` 第 1 脚。测 `TP1`。
- 预期：`TP1` 为低，`TP5` 为低，给释放脉冲执行器不动作。
- 不合格处置：查 `R1`、`R2`、`C1` 与 `U1` 第 1 脚。

### T5 FIRE_INHIBIT_N 短到 GND

- 操作：把 `FIRE_INHIBIT_N` 短到 `GND`。
- 预期：同 T4，`TP5` 为低。
- 不合格处置：同上。

### T6 EXTERNAL_ALLOW 断开

- 操作：断开 `J3` 第 3 脚。
- 预期：`TP2` 为低，`TP5` 为低，执行器不动作。
- 不合格处置：查 `R3`、`R4`、`C2` 与 `U1` 第 2 脚。

### T7 MECH_RECOVERED_RAW 断开

- 操作：断开 `J3` 第 5 脚。测 `TP3`。
- 预期：`TP3`（`MECH_RECOVERED_N`）为低，`TP5` 为低，给 `PRELOAD_CMD` 预载也不动作。
- 不合格处置：查 `R7` 上拉与 `U5A`。

### T8 MECH_RECOVERED_RAW 短到 GND（危险方向，仅记录）

- 操作：把 `MECH_RECOVERED_RAW` 短到 `GND`，其余条件仍不满足。
- 预期：`TP3` 为高，`MECH_RECOVERED_N` 这一路放行。这是短路到地造成的伪复位，属于
  单点失效，本版没有自动检出。
- 不合格处置：本步用于确认危险方向真实存在。若在其余条件里再把 `ARMED_LATCH` 与主使能
  人为置位，就不该继续，测试到此为止。记录现象，作为补双通道触点的依据。

### T9 POCKET_ALIGNED 断开（模式 B）

- 操作：拔掉 `JP1`，断开 `J3` 第 7 脚。
- 预期：`TP4`（`POCKET_OR_MODE_A`）为低，`TP5` 为低，执行器不动作。
- 不合格处置：查 `R5`、`R6`、`D8`、`R26`。

### T10 模式 A 旁路成立与撤销

- 操作：`JP1` 装好。先让供给盘触点闭合（`J6` 的 1、2 脚短接）测 `TP4`；再断开触点测
  `TP4`。
- 预期：触点闭合时 `TP4` 为高，旁路成立；触点断开时 `TP4` 变低，旁路撤销。
- 不合格处置：查 `D7`、`R27`、`JP1` 与 `J6` 接线。这一条同时验证 H3。

## 3. MCU 卡死与单稳态

### T11 释放命令持续高

- 操作：其余条件人为置到允许侧，把 `MCU_RELEASE_CMD` 接到 `+3V3` 并保持。示波器单次
  捕获 `TP7`（`RELEASE_PULSE`）与执行器电流。
- 预期：`TP7` 只出现一个脉冲，宽度在 30 到 40 ms 之间（设计值约 33 ms），之后保持低。
  执行器只在脉冲期间通电，不会一直通电。
- 不合格处置：若脉冲持续高，查 `U2A` 的 A 端是否接 `GND`、`R19`/`C15` 是否装对。
  若宽度明显偏离，先按实测值换 `C15` 再复测。

### T12 释放命令重复翻转

- 操作：在释放脉冲有效期内，用信号源以 1 kHz 反复翻转 `MCU_RELEASE_CMD`。
- 预期：`RELEASE_PULSE` 可能被续长，这是 74HC123 可重触发的特性。记录现象。
- 不合格处置：固件须保证释放脉冲期内不再翻转该引脚。若无法保证，改用不可重触发的
  单稳或加触发封锁，改版前把这条列为待办。

## 4. 锁存器

### T13 武装锁存置位与保持

- 操作：`Q1` 条件满足时给 `ARM_CMD`（`J3` 第 9 脚）一个高脉冲，然后断开。
  测 `J9` 第 2 脚（`ARMED_LATCH`）。
- 预期：`ARMED_LATCH` 变高并保持；断开 `ARM_CMD` 后仍为高。`Q1` 条件随后撤销，
  `ARMED_LATCH` 仍保持。
- 不合格处置：查 `U4B`、`U3B` 的 D 端上拉与时钟接线。

### T14 释放后自动清零

- 操作：在 T13 的已武装状态下给一次释放脉冲，测 `ARMED_LATCH`。
- 预期：释放脉冲结束后 `ARMED_LATCH` 变低，一次武装对应一次释放。
- 不合格处置：查 `U5C` 与 `U4C` 的 `REL_IDLE` 通路。

### T15 DISARM_CMD 清零

- 操作：重新武装，然后给 `DISARM_CMD`（`J3` 第 11 脚）高。
- 预期：`ARMED_LATCH` 变低。
- 不合格处置：查 `U5D` 与 `U4C`。

### T16 故障锁存置位与保持

- 操作：把 `FAULT_SET_N` 短暂拉低（可短接 `J7` 的 5、6 脚），然后松开。测 `TP8`。
- 预期：`FAULT_LATCH` 变高并保持，松开后仍为高。`J9` 第 1 脚为高，故障指示灯亮。
- 不合格处置：查 `U3A` 的置位端与 `R29`。

### T17 故障切断主使能与预载

- 操作：在故障锁存保持时，把主使能与 `PRELOAD_CMD` 置到有效侧。
- 预期：`MASTER_ENABLE_GATED` 为低，`Q2_OUT` 为低，`PRELOAD_ENABLE` 为低，执行器与
  预载都不动作。
- 不合格处置：查 `U5B`、`U6A`、`U6B`、`U6D`。

### T18 故障复位必须重新归零

- 操作分三步。第一，故障保持时把三处 HOME 同时置高，保持几秒；测 `FAULT_LATCH` 是否变化。
  第二，把三路 HOME 全部置低，再把三路同时置高，捕获 `FAULT_RESET_N` 与 `FAULT_LATCH`。
  第三，只把其中两路置高，第三路保持低。
- 预期：第一步不动，因为已有电平没有上升沿，锁存保持。第二步 `FAULT_RESET_N` 出现约
  22 ms 低脉冲，随后 `FAULT_LATCH` 变低。第三步不产生复位，锁存继续保持。
- 不合格处置：查 `U4A`、`U2B`、`R30` 与三路 HOME 的下拉。这一条直接验证 H4 的复位条件。

### T19 上电复位

- 操作：反复断电、上电五次，每次立刻测 `FAULT_LATCH`、`ARMED_LATCH`、`Q2_OUT`。
- 预期：每次上电三者都是低。
- 不合格处置：查 `R28`、`C14`、`D11`、`D12`。

## 5. 急停

### T20 急停三个作用

- 操作：执行轨有电，其余条件人为置到允许侧并武装。按急停，分别测 `V_ACT_SW`、
  `MASTER_ENABLE_GATED`、`FAULT_LATCH`，然后复位急停。
- 预期：按下后 `V_ACT_SW` 变 0，`MASTER_ENABLE_GATED` 变低，`FAULT_LATCH` 置高并保持。
  松开急停后故障仍锁存，必须按 T18 重新归零才解除。
- 不合格处置：查 `J7` 三个触点的接线与 `R18`。这一条验证 H6。

## 6. 预载物理互锁

### T21 机构未复位时预载无回流

- 操作：断开 `J4` 第 3 脚（`MECH_RET`）到地的常闭触点，给 `PRELOAD_CMD` 高。
- 预期：预载执行器无电流，`MECH_RET` 端没有到地的回路。
- 不合格处置：查 `M2` 源极是否确实只在 `J4` 第 3 脚回地，没有被到板地的走线旁路。
  这一条验证 H2。

### T22 预载使能与故障

- 操作：触点接好时给 `PRELOAD_CMD`，预载动作；再置故障锁存后重复。
- 预期：无故障时预载动作；故障时 `PRELOAD_ENABLE` 为低，预载不动作。
- 不合格处置：查 `U6B`、`U6D`。

## 7. 与门真值表

### T23 逐组合遍历

- 操作：把 `FIRE_INHIBIT_N`、`EXTERNAL_ALLOW`、`MECH_RECOVERED_RAW`、`POCKET_OR_MODE_A`、
  `ARMED_LATCH`、`MASTER_ENABLE_GATED` 六个量按 2 的 6 次方组合逐一设置，每个组合点一次
  释放脉冲，记录 `TP6`（`Q2_OUT`）与执行器电流。
- 预期：只有六个量全为允许侧、且释放脉冲到来时，`Q2_OUT` 才在脉冲期间为高，执行器才
  有电流；其余组合同样给脉冲都不动作。
- 不合格处置：按组合表定位到具体门。Q1 相关的组合查 `U1` 的前半与四路输入；Q2 相关的
  组合查 `U1` 的后半、`U3B`、`U2A`、`U6A`。

## 8. 验收判据

以下全部满足才算本板通过 §6.11 第一条：

- T1、T2、T3 无电流。
- T4 到 T10 每条断开都使执行器不动作，T8 记录到危险方向。
- T11 的单脉冲机制成立，宽度在实测确认的容差内。
- T16 到 T19 的锁存与复位行为正确，尤其是 T18 的“无上升沿不复位”。
- T20 三个急停作用都在，且不经 MCU。
- T21 的物理回流断开有效。
- T23 的真值表没有反例。

任一条不通过，本板不得进入联调，先改板或改件再复测。

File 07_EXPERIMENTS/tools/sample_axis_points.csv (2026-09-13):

px | py | pan_deg | tilt_deg
20.0 | 20.0 | -29.66762 | 19.84422
160.0 | 18.0 | -0.06041 | 22.93447
300.0 | 22.0 | 29.37762 | 19.99025
18.0 | 120.0 | -30.39902 | 0.55100
160.0 | 120.0 | -0.50174 | 0.76836
302.0 | 120.0 | 29.38789 | 1.10199
22.0 | 220.0 | -30.06628 | -18.86976
160.0 | 222.0 | -0.92203 | -21.33510
298.0 | 218.0 | 28.25225 | -17.90003
90.0 | 60.0 | -16.04867 | 13.60463
230.0 | 60.0 | 15.45632 | 13.92973
90.0 | 180.0 | -16.53946 | -12.34855
230.0 | 180.0 | 15.00696 | -12.04385

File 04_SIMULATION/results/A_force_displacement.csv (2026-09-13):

x_m | force_N
0.0 | 0.0
2e-05 | 0.002464161327718914
4e-05 | 0.004929325193093459
6.000000000000001e-05 | 0.007396494133779265
8e-05 | 0.009866670687431963
0.0001 | 0.012340857391707186
0.00012000000000000002 | 0.014820056784260564
0.00014000000000000001 | 0.017305271402747728
0.00016 | 0.019797503784824304
0.00018 | 0.022297756468145927
0.0002 | 0.02480703199036823
0.00022 | 0.027326332889146838
0.00024000000000000003 | 0.029856661702137396
0.00026000000000000003 | 0.03239902096699551
0.00028000000000000003 | 0.03495441322137684
0.00030000000000000003 | 0.03752384100293699
0.00032 | 0.04010830684933161
0.00034 | 0.04270881329821632
0.00036 | 0.04532636288724675
0.00038 | 0.04796195815407855
0.0004 | 0.05061660163636732
0.00042 | 0.053291295871768715
0.00044 | 0.055987043397938356
0.00046 | 0.058704846752531875
0.00048000000000000007 | 0.06144570847320492
0.0005 | 0.06421063109761307
0.0005200000000000001 | 0.06700061716341202
0.00054 | 0.06981666920825737
0.0005600000000000001 | 0.07265978976980476
0.00058 | 0.07553098138570978
0.0006000000000000001 | 0.07843124659362814
0.00062 | 0.08136158793121538
0.00064 | 0.08432300793612722
0.0006600000000000001 | 0.08731650914601924
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

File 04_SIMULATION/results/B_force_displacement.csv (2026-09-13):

base_pos_m | x0_m | input_force_N
0.0 | -2.164912482613444e-14 | -2.667166184092129e-12
1.1676396997497914e-05 | 1.0648533862648815e-05 | 0.0013119215231547118
2.335279399499583e-05 | 2.129661034349934e-05 | 0.002623937998368886
3.5029190992493745e-05 | 3.194412070460928e-05 | 0.003936187287828319
4.670558798999166e-05 | 4.259095628569901e-05 | 0.005248807202678572
5.838198498748957e-05 | 5.323700828900893e-05 | 0.006561935461067686
7.005838198498749e-05 | 6.388216771459783e-05 | 0.007875709664683702
8.17347789824854e-05 | 7.452632548910482e-05 | 0.009190267299136516
9.341117597998332e-05 | 8.516937247628694e-05 | 0.010505745719768568
0.00010508757297748124 | 9.581119962720922e-05 | 0.011822282154752782
0.00011676396997497914 | 0.00010645169785659878 | 0.013140013674378464
0.00012844036697247705 | 0.00011709075790426766 | 0.014459077158404707
0.00014011676396997498 | 0.00012772827048916613 | 0.015779609299634702
0.0001517931609674729 | 0.00013836412631979916 | 0.01710174658976244
0.0001634695579649708 | 0.00014899821622939367 | 0.018425625320785226
0.00017514595496246873 | 0.00015963043109986898 | 0.019751381560240387
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

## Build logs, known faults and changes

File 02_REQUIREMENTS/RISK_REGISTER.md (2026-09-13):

# MST-01 风险台账（RISK_REGISTER.md）

本文件对应主规格 §33 交付项。每条风险按编号、风险描述、类别、可能性、影响、现有缓解措施、
残余风险、验证方式、触发后的行动九个字段记录。类别取安全、技术、成本、进度四类，
可能性与影响取高、中、低三档，是当前设计阶段的主观判断，有数据后回填。

残余风险写的是采取现有缓解措施之后仍剩下的部分。标了「无有效缓解」的条目是单点失效分析里
目前没有对策的，需要优先处理。风险来源覆盖统一架构方案 §9 的三条高风险、§6.11 的三条先验证项、
§30 的五条 STOP、§21 成本，以及 §25.2、§29 的研究价值问题。

术语与故障码对应 `05_FIRMWARE/src/aim_types.h` 的 FaultCode 枚举：
NONE=0、PERIPH_INIT=1、HOME_TIMEOUT=2、HOME_SWITCH_CONFLICT=3、RELEASE_GATE_SELFTEST=4、
OBS_LINK=5、INDEX_FAIL=6、WATCHDOG=7、MECH_STUCK=8、ESTOP=9。软故障可经 SAFE → HOME → READY 恢复，
硬故障锁存。

---

## 一、安全类

### RSK-01 释放门控硬件在体量内落不下，或失效时不落安全侧

- 风险描述：H1 与门树加负载开关加单稳态，在火柴盒体积内可能布不下；或者断线、失电时不能可靠落到禁止侧，
  导致 MCU 卡死也能放出能量。
- 类别：安全
- 可能性：中
- 影响：高
- 现有缓解措施：架构 §6.6 给出完整与门树、负载开关、单稳态与下拉方案；输入按极性加下拉或上拉，开路即安全侧；
  架构 §6.11.1 要求先用小板验证释放链。
- 残余风险：方案目前只有设计意图，没有实物。与门树、单稳态、冗余触点在目标体积内的布局未出图，
  任何一处为省空间被删都会削弱安全完整性。
- 验证方式：搭只有释放链和与门的小板，逐条故意断开输入、故意让 MCU 输出常高，确认释放无动作。
- 触发后的行动：H1 不通过则暂停状态机与集成工作，先解决释放链（架构 §6.11.1）。

### RSK-02 FIRE_INHIBIT 或 EXTERNAL_ALLOW 短路到高，fail-safe 丢失

- 风险描述：两条许可线的失效方向靠下拉保证，只覆盖断线、掉电、接插件松脱。信号被短路到 3V3 时会被当成许可，
  释放链失去否决能力。
- 类别：安全
- 可能性：低
- 影响：高
- 现有缓解措施：两条线用下拉，只有主动驱动为高才算许可；软件先判 FIRE_INHIBIT 再判 EXTERNAL_ALLOW，
  日志分别记录（架构 §6.7）。
- 残余风险：架构 §6.7 提出的双冗余触点交叉校验和「信号长时间无跳变」卡死诊断都还没实现，只是留了位置。
  短路场景目前没有有效缓解，这是单点失效分析里没有对策的项之一。
- 验证方式：故意把两条信号线短到 3V3，观察系统是否仍落在禁止侧；做双通道一致性测试。
- 触发后的行动：在双通道校验和卡死诊断落地前，不把这路信号当独立安全层。评审若判定不可接受，
  加外部安全继电器或独立硬件看门狗。

### RSK-03 MECH_RECOVERED 误报为已复位

- 风险描述：MECH_RECOVERED 是 Interlock 1 的唯一依据，误报为真时系统会在机构未复位时进入 PRELOAD。
  该信号走慢速 I2C 扩展器，读取延迟与可靠性未验证。
- 类别：安全
- 可能性：中
- 影响：高
- 现有缓解措施：Interlock 1 用常闭干接点串在预载驱动使能里，机构没复位就物理断驱动（架构 §6.5 H2、§6.6）；
  软件复查该信号并做诊断日志。
- 残余风险：微动开关的机械寿命、开关力对复位位置的影响、慢速 I2C 读取是否够快都未测。硬件常闭触点
  降低了后果，但误报本身仍会发生。
- 验证方式：MST-01B 阶段专门测该信号时序与可靠性，含微动开关力对复位位置的影响（架构 §6.10 状态信号选型）。
- 触发后的行动：误报率不可接受则改直连 GPIO 或双冗余触点；在证实前不放宽 Interlock 1。

### RSK-04 ARMED 态不能安全卸载

- 风险描述：机构一旦完成预载，可能只能通过释放泄掉储能，没有安全 dump 通道。ARMED 期间的中止就只能停在
  FAULT 并保持硬件断开。
- 类别：安全
- 可能性：中
- 影响：中
- 现有缓解措施：状态机预留受控卸载路径（架构 §6.2），但机构是否有该能力未定。
- 残余风险：A/B/C 阶段是否支持安全卸载完全未知。不支持的话状态机可用性明显下降，
  ARMED 停留时长和指向门的设计都要跟着改。
- 验证方式：A/B/C 阶段一并验证，看能否在不触发释放的前提下泄掉储能（架构 §6.11 末）。
- 触发后的行动：不支持则把所有 ARMED 中止一律锁 FAULT 加硬件断开，记录到 10_FAILURE_ANALYSIS，
  再评估是否加独立 dump 通道。

### RSK-05 开环舵机上电归零不可靠

- 风险描述：参考开关重复定位精度不足，或 tilt 带重力负载时低速驱向参考方向失败，导致归零失败或基准偏移。
- 类别：安全
- 可能性：中
- 影响：高
- 现有缓解措施：参考开关加 3 秒超时，失败进 FAULT 且释放链保持断开；上电时释放链先被硬件固定在禁止侧；
  优先用总线舵机位置做校验（架构 §6.10、§6.11.3）。
- 残余风险：候选舵机的多次上电零位散布未测。归零不可靠会让系统朝错误方向释放，失败进 FAULT 能兜住，
  但反复失败会让系统不可用。
- 验证方式：多次上电记录零位散布；故意把舵机拨偏后上电；测归零耗时（架构 §6.11.3）。
- 触发后的行动：精度不够或失败率高则改冗余开关或换舵机；通过前不放行进入 AIM_ALLOWED。

### RSK-06 开环舵机非归零时段卡死，无检测手段

- 风险描述：云台运行中舵机堵转或卡死，系统可能静默失位或停在错误指向继续动作。
- 类别：安全
- 可能性：中
- 影响：高
- 现有缓解措施：架构 §6.10 给出电流、母线电压跌落、到位超时、电流积分热模型等候选判据；
  检测到失速先停轴、回退、重试一次，仍失败标记该轴退化并禁 AIM_ALLOWED。
- 残余风险：这些判据都还没标定，开环舵机在非归零时段卡死目前没有检测手段。架构 §6.10 已明确指出
  「速度长时间为零而 duty 高」的旧判据在舵机上不适用。这是单点失效分析里没有对策的项之一。
- 验证方式：对候选舵机做定角阶跃、记录电流波形、标定堵转阈值，确认不误报不漏报（架构 §6.11.3）。
- 触发后的行动：标定不成立前把该轴视为不可信；卡死发生在储能态或与机构卡死耦合时升级 FAULT。
  参见失效模式 FM-15。

---

## 二、技术类

### RSK-07 视觉处理拖后 PRELOAD/RELEASE 时序

- 风险描述：单片方案下视觉循环与发射时序共用一个 CPU。时序被拖后轻则脉冲不一致，重则机构停在中间态。
- 类别：技术、进度
- 可能性：中
- 影响：高
- 现有缓解措施：非阻塞状态机加固定节拍控制环；PRELOAD/RELEASE 放定时器中断或独立任务，
  不排在视觉处理后面；消除跨 MCU 延迟（架构 §3.1、§9.1；REQ-161）。
- 残余风险：两者仍共享一个 CPU，最坏情况下的时序抖动没有实测。抖动阈值也没有定义。
- 验证方式：第二期实测最坏情况下 PRELOAD/RELEASE 的时序抖动（架构 §9.1）。
- 触发后的行动：抖动超标且任务隔离压不下去，评估把发射时序移到独立硬件，或回到双 MCU 方案。

### RSK-08 舵机开环指向精度不足

- 风险描述：失去编码器后，舵机死区、回差、温漂直接进入瞄准误差；提前量只能靠标定延迟常数补偿，
  精度会下降。
- 类别：技术
- 可能性：中
- 影响：中
- 现有缓解措施：保留像素到角度标定；用标定延迟常数补偿提前量；总线舵机回报位置（架构 §7、§6.10）。
- 残余风险：还能不能把目标锁在画面死区内未验证。精度下降属于换体量的已知代价，但下降幅度没有数据。
- 验证方式：MST-01A 阶段量静态指向重复性（架构 §9.2）。
- 触发后的行动：精度不足则缩小死区要求、提高标定频率，或重评执行机构。

### RSK-09 单级相对普通膜片无可测优势（STOP-01）

- 风险描述：MST-01B 单级 snap 相对 MST-01A 普通膜片没有可测优势。
- 类别：技术
- 可能性：中高
- 影响：高
- 现有缓解措施：A/B/C 对照强制做，A1 建立基线，测量变量按 §15.2 固定。
- 残余风险：这是项目核心假设的边界。真无可测优势的话，两级、PRELOAD 链、旋转供给盘的必要性都会塌掉。
  SRC-05 已提示 snap 转流体有损失，不能预设增益。
- 验证方式：A1 与 B1 的 force-displacement、膜片响应时间、压力曲线、重复性。
- 触发后的行动：按 STOP-01 停止双级研究；按架构 §6.8 落成构建期机构变体常量加研究门控标志，不进 FAULT。

### RSK-10 双级相对单级更差（STOP-02）

- 风险描述：MST-01C 双级相对 B 更复杂、更不稳定、寿命下降，而脉冲没有明显改善。风险的实质是双级机构的复杂度与收益不匹配。
- 类别：技术
- 可能性：中
- 影响：高
- 现有缓解措施：C1 要求判定两级事件是否可分辨、顺序是否固定、是否偶发同时 snap（§16）。
  `TEST_PLAN.md` 的 C1 通过标准处已写入模型的先验预测，作为实验要证伪或证实的对象；
  `DESIGN_DECISION_LOG.md` 的 D-14 记录了当前倾向、支持证据、反对证据与待补实验。
- 残余风险：引入第二级会增加装配与标定面，即使动态结果勉强，也可能因可靠性和成本被淘汰。
  `04_SIMULATION/` 的纯软件模型（非实测）进一步压低了收益预期：名义参数下 C 相对 B 的膜片峰值速度只高约 18%
  （模型 10.573 对 8.939 m/s），输入功接近翻倍（模型 37.623 对 19.963 mJ）；级序在刚度失配 1.5 倍时翻转，
  级间间隔在模型里于 2.32 到 7.20 ms 之间漂移。模型并未干净命中 STOP-02，「响应没有区别」不成立（存在 18% 差异），
  寿命按 §17 尚未测。模型可信度受 `k_bar` 无实测、膜片粘弹未建模、流体耦合缺失三项限制。
- 验证方式：B1 与 C1 的动态数据，加上 §17 的 100/500/1000 寿命阶梯。C1 重点核对模型先验预测
  （级序稳定性、inter-stage delay 散度、相对 B1 的增益幅度）。
- 触发后的行动：实测复现模型倾向且寿命也下降，按 STOP-02 回退单级，记录到 10_FAILURE_ANALYSIS（架构 §6.8）。
  实测给出实质增益则保留双级，并回查模型哪条假设失真（`k_bar`、膜片粘弹、流体耦合），修订后再解释。

### RSK-11 边界切换没有稳定可复现的输出差异（STOP-03）

- 风险描述：D 版的 BOUNDARY_0 与 BOUNDARY_1 之间，输出差异不稳定或不可复现。
- 类别：技术
- 可能性：中
- 影响：中
- 现有缓解措施：D1 至少对比两个边界状态的 force-displacement、stage order、inter-stage delay、membrane response（§16）。
- 残余风险：邻近 prior art 多（SRC-03、SRC-04），留给 MST-01 的只有小型装置里的可重复映射。
  关键词是可重复，可调不等于可重复。
- 验证方式：D1 的重复性数据。
- 触发后的行动：按 STOP-03，D 版不进入论文主线，记录并关闭边界研究分支（架构 §6.8）。

### RSK-12 旋转供给盘频繁卡料（STOP-04）

- 风险描述：软圆片在盘内翘曲、叠片、静电吸附，导致索引失败、双片或错位。
- 类别：技术、进度
- 可能性：中高
- 影响：中
- 现有缓解措施：供给先脱离炮头独立跑（§18）；INDEX 单次重试并记 jam；连续失败或检出双片、错位则禁 Mode B、
  保留 Mode A（架构 §6.8）；独立 pocket 降低叠片概率。
- 残余风险：50 次人工复位不超过 1 次的量化门槛已经定下（附录 C-07），但真实盘内的翘曲、静电现象还没有数据。
  卡在储能态且机构顶死时会升级为 FAULT。
- 验证方式：M1 独立 50 次索引，记录 index_command、index_detected、jam、double_feed、misalignment、manual_reset。
- 触发后的行动：超过 1 次即 STOP-04，先修供给，不与炮头集成。

### RSK-13 传感靶扰动 snap 动力学

- 风险描述：STAGE1_STATE、STAGE2_STATE 用霍尔锁存，磁钢靶会改变 snap 动力学，让测量手段本身修改被测对象。
- 类别：技术
- 可能性：中
- 影响：中
- 现有缓解措施：靶可旋拧拆下，方便做带靶与不带靶对照；靶附近件用 304 不锈钢（近无磁），不用 301（架构 §6.10）。
- 残余风险：带靶与不带靶的 force-displacement 差异未知。架构 §6.10 明确要求实验确认，不能在设计中拍板。
- 验证方式：带靶与不带靶的 force-displacement 对照（架构 §6.10 状态信号选型）。
- 触发后的行动：差异显著则改传感位置、换无接触光电器件，或把靶移到对动力学不敏感的构件上。

### RSK-16 供给模块与 §1.2 尺寸目标冲突

- 风险描述：§1.2 给核心脉冲模块的 envelope 为长约 30–50 mm、横向约 15–25 mm，允许加供给模块后略大。
  `03_CAD/MST-01E` 的几何自检（非实测）给出包围盒：单级加 6 位供给盘 58.00 × 58.00 × 46.25 mm，
  单级加 8 位 69.04 × 69.04 × 46.25 mm，双级加 6 位 58.00 × 58.00 × 58.25 mm，双级加 8 位 69.04 × 69.04 × 58.25 mm。
  供给盘之外的核心模块横向仍是 22 mm，在 envelope 内。装盘后横向超出上限 33.00 mm（6 位）到 44.04 mm（8 位），
  轴向双级配置也超出 8.25 mm。按当前载荷尺寸与位数，供给模块与 §1.2 的尺寸目标冲突，
  §1.2 允许的「略大」不足以覆盖，需一并裁决。
- 类别：技术
- 可能性：高（几何自检已确认，非建模误差）
- 影响：中
- 现有缓解措施：§1.2 允许加供给模块后略大（REQ-027）；D-03 已定 8 位明显变大时先做 6 位（REQ-151）；
  REQ-152 要求结构过大时先保证重复性再缩小。这些措施覆盖不了 33 mm 以上的横向超出。
- 残余风险：超出由几何约束决定，与建模误差无关。软圆片直径 14 mm 时，6 位需要分布圆半径 18 mm、
  8 位需要 23.52 mm，相邻座圈不干涉条件 `2R·sin(π/N) ≥ 座圈外径 + 间隙` 决定位数越多半径越大。
  减到 6 位仍超出 33 mm，现有「略大」口径不成立，须由尺寸目标与位数一并裁决，见 D-15。
- 验证方式：`03_CAD/MST-01E` 的几何自检（已完成，非实测）；裁决前补做载荷直径缩小、4 位方案、
  Mode A/B 分体与可拆卸供给盘的盘径与包围盒重算。
- 触发后的行动：按 D-15 的候选方案在尺寸目标与供给盘位数之间裁决，未定前不冻结 Mode B 整机尺寸。

---

## 三、成本类

### RSK-14 炮头机械架构成本超过 ¥50（STOP-05）

- 风险描述：实际选型、件数、加工方式定下来后，炮头机械架构超过 ¥50 硬限制。
- 类别：成本
- 可能性：中
- 影响：中
- 现有缓解措施：`06_BOM/bom.csv` 9 项区间求和为 ¥17–46，硬限小于 ¥50；超预算按 §21 顺序削减：
  非必要轴承、CNC 或金属定制件、装饰壳、不必要的传动级。状态检测、防脱结构、必要密封、安全互锁不得删。
- 残余风险：上限 ¥46 已经高于推荐值 ¥40，按上限采购时就必须先砍。目前只有设计预算，没有实际报价，
  件数与加工方式也随 CAD 变化。
- 验证方式：出图后按 bom.csv 核对件数与规格；结构冻结后做 BOM 校验门槛（架构 §6.8）。
- 触发后的行动：按 §21 顺序削减。若砍到不可删项才能达标，重评机械方案，不删安全与状态检测项。

---

## 四、进度与研究价值类

### RSK-15 prior art 密度过高，研究价值不足

- 风险描述：14 条机制层面来源风险等级极高，能留的空间只有「多级失稳加被动膜片」的特定瞬态耦合，
  以及小型系统中边界状态到脉冲时间历程的可重复映射。这两条都还没数据，也可能证明没有规律。
- 类别：进度、技术
- 可能性：中
- 影响：中
- 现有缓解措施：研究问题从「发明没人见过的发射器」改成研究瞬态耦合规律（§29）；
  `01_PRIOR_ART/CLAIM_MATRIX.md` 明确列出仅剩的三条立足点与各自缺口。
- 残余风险：不保证这两条能产出一条可发表的研究结论；具体结构组合要等冻结后才能做 claim-level 查新，
  当前无法评估。
- 验证方式：A/B/C/D 的动态数据能否支撑一个稳定、可重复、可区分的结论；结构冻结后做 claim-level 检索。
- 触发后的行动：数据也说明耦合无规律或无研究价值，则收缩为工程交付物，不再主张研究贡献，专利暂不推进。

---

## 五、残余风险统计与优先级

16 条风险全部写有残余风险，没有空项。其中没有有效缓解措施或没有检测手段的有三条：

- RSK-02 FIRE_INHIBIT 或 EXTERNAL_ALLOW 短路到高，只有设计占位，未实现双通道校验。
- RSK-06 开环舵机非归零时段卡死，候选判据未标定，当前无检测手段。
- RSK-04 ARMED 态安全卸载能力未定，实际没有可用的卸载通道。

按架构 §1.1 的优先级（安全大于可重复性大于可靠性大于小型化大于成本大于输出强度），
处理顺序建议为 RSK-01、RSK-02、RSK-03、RSK-04、RSK-05、RSK-06，技术类里先做 RSK-09，
因为 STOP-01/02 决定后面整条链要不要做。

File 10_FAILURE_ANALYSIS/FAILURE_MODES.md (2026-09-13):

# MST-01 失效模式分析（FAILURE_MODES.md）

本文件对应主规格 §33 交付项，记录机械、电气、固件三类的失效模式。每条按编号、失效模式、所属模块、
检测手段、系统响应、严重度、是否已有缓解组织。系统响应写清对应哪个 FaultCode 或哪条状态转移。

FaultCode 取自 `05_FIRMWARE/src/aim_types.h`：NONE=0、PERIPH_INIT=1、HOME_TIMEOUT=2、
HOME_SWITCH_CONFLICT=3、RELEASE_GATE_SELFTEST=4、OBS_LINK=5、INDEX_FAIL=6、WATCHDOG=7、
MECH_STUCK=8、ESTOP=9、MEMBRANE_RUPTURE=10、DOUBLE_FEED=11、FIRE_INHIBIT_SHORT=12、
I2C_BUS_HANG=13、STATE_ILLEGAL=14。软故障 HOME_TIMEOUT、OBS_LINK、INDEX_FAIL、WATCHDOG、
ESTOP、DOUBLE_FEED 可经 SAFE → HOME → READY 恢复；硬故障 PERIPH_INIT、HOME_SWITCH_CONFLICT、
RELEASE_GATE_SELFTEST、MECH_STUCK、MEMBRANE_RUPTURE、FIRE_INHIBIT_SHORT、I2C_BUS_HANG、
STATE_ILLEGAL 锁存，软件清除无效。

原先找不到对应 FaultCode 的失效模式已在枚举末尾补齐，逐个对照见第五节。
没有在线检测手段的条目单独标出，集中列在文末。

---

## 一、机械类

### FM-01 参考开关卡滞

- 所属模块：云台与供给盘（PAN_HOME、TILT_HOME、MAG_HOME）
- 检测手段：归零超时，3 秒内未触发或触发后丢失即失败；开关在三处 HOME 与门里的状态矛盾也能暴露部分问题。
- 系统响应：HOME_TIMEOUT(2) 或 HOME_SWITCH_CONFLICT(3) → FAULT → SAFE。释放链保持硬件断开，绝不进 READY。
- 严重度：高
- 是否已有缓解：有。参考开关加超时；故障锁存器复位条件接三处 HOME 开关的与，机构没真回零位就复位不了。

### FM-02 机构卡在中间态

- 所属模块：机械脉冲核心（STAGE_1、STAGE_2、膜片）
- 检测手段：MECH_RECOVERED 长时间为假；到位时间超时；STAGE1_STATE、STAGE2_STATE 与预期不符。
- 系统响应：MECH_STUCK(8) 硬故障，锁存；预载驱动使能由常闭触点物理断开；软件清除无效。
- 严重度：高
- 是否已有缓解：有。Interlock 1 用常闭干接点串在预载驱动使能里（架构 §6.5 H2）。

### FM-03 膜片破裂

- 所属模块：DIAPHRAGM_MODULE
- 检测手段：**无在线检测**。压力波形异常或气密性下降可在测试后看出，运行中靠人工目视与实验后检查。
- 系统响应：MEMBRANE_RUPTURE(10) 硬故障，锁存。目前无在线检测，靠人工检出后置位；操作者停止动作、更换膜片、记录，破裂导致的异常曲线在数据处理阶段剔除并复测。
- 严重度：中
- 是否已有缓解：部分。可拆压环便于检查与更换；§17 寿命检查含裂纹项。

### FM-04 弹性元件疲劳

- 所属模块：STAGE_1、STAGE_2 弹性片
- 检测手段：**无在线检测**。靠 force-displacement 漂移与 §17 寿命阶梯离线判断。
- 系统响应：无对应 FaultCode。寿命测试中记录漂移，超阈值停用该件。
- 严重度：中
- 是否已有缓解：部分。独立弹性元件便于更换；PET 做几何验证，弹簧钢做寿命版。

### FM-05 供给盘卡料

- 所属模块：MAGAZINE_MODULE
- 检测手段：index_detected 未在超时内到位；MAG_INDEX_OK 超时。
- 系统响应：INDEX_FAIL(6) 软故障；INDEX 状态内重试一次；连续失败或检出双片、错位则禁 Mode B、保留 Mode A；
  若卡在储能态且机构顶死，升级 FAULT 并保持硬件断开（架构 §6.8）。
- 严重度：中
- 是否已有缓解：有。单次重试加量化门槛，50 次人工复位不超过 1 次。

### FM-06 双片

- 所属模块：MAGAZINE_MODULE、PAYLOAD_MODULE
- 检测手段：**无专用传感器**。只能靠人工、视频或出膛异常发现；M1 里作为记录字段，不构成实时判据。
- 系统响应：DOUBLE_FEED(11) 软故障，检出后禁 Mode B；通过 CLEAR 清除，待修供给。
- 严重度：中
- 是否已有缓解：部分。旋转盘独立 pocket 降低叠片概率；§18 把 double_feed 列为记录项。

### FM-07 错位（载荷未对齐）

- 所属模块：MAGAZINE_MODULE、释放门控
- 检测手段：POCKET_ALIGNED 或 MAG_INDEX_OK 用霍尔或光电对射，接入 H1 与门。
- 系统响应：硬件与门拒绝释放，模式 B 无法完成；软件侧按 INDEX_FAIL(6) 或对齐失败升级软故障并禁 Mode B。
- 严重度：高
- 是否已有缓解：有。对齐开关接入 H1（架构 §6.5 H3、§6.6）。

---

## 二、电气类

### FM-08 FIRE_INHIBIT 短路到高

- 所属模块：安全输入，释放门控 H1
- 检测手段：**无检测手段**。架构 §6.7 提出双冗余触点交叉校验与「信号长时间无跳变」卡死诊断，尚未实现。
- 系统响应：fail-safe 丢失，短路会被当成许可，释放链可能被误允许。无自动响应。
- 严重度：极高
- 是否已有缓解：无有效缓解。下拉只防断线、掉电、接插件松脱，防不了短路到 3V3。对应风险 RSK-02。

### FM-09 I2C 总线卡死

- 所属模块：HAL、I2C0、MCP23017
- 检测手段：I2C 事务超时或 NACK；读取的慢速信号（MECH_RECOVERED、MAG_INDEX_OK 等）持续不变。
- 系统响应：慢速输入不可信。释放链与预载使能不依赖 I2C，硬件仍独立。I2C_BUS_HANG(13) 硬故障，
  置 FAULT 并保持硬件断开；PERIPH_INIT(1) 只覆盖上电初始化失败，运行期总线故障由前者单列。
- 严重度：高
- 是否已有缓解：部分。释放门控与预载使能不经 I2C（架构 §6.6）。

### FM-10 MCU 卡在输出高（RELEASE_CMD）

- 所属模块：MCU、释放执行器
- 检测手段：MCU 自身卡死无法自检，靠外部单稳态与看门狗。
- 系统响应：74HC123 单稳态把驱动时间钳成固定短脉冲，不会持续通电；看门狗超时 WATCHDOG(7) → SAFE。
  释放仍受与门 H1 约束。
- 严重度：高
- 是否已有缓解：有设计，待实物验证（架构 §6.6）。§6.9 第 9 条指出旧看门狗升级条件不可达，已改 esp_task_wdt。

### FM-11 电源跌落复位

- 所属模块：电源、MCU
- 检测手段：欠压复位（Brownout）；上电后重新走 BOOT → SAFE → HOME。
- 系统响应：上电瞬间释放链被硬件固定在禁止侧，预载使能断开（架构 §6.6、§6.10）；归零完成前不许动作。
- 严重度：高
- 是否已有缓解：有。硬件上电默认禁止侧，强制走 HOME 流程。

---

## 三、固件类

### FM-12 看门狗超时

- 所属模块：固件
- 检测手段：esp_task_wdt 或独立硬件看门狗。
- 系统响应：WATCHDOG(7) 软故障；超时直接进 SAFE（架构 §6.9 第 9 条）。
- 严重度：高
- 是否已有缓解：有。旧实现升级条件不可达，需按 §6.9 改成超时即升级。

### FM-13 状态机进入不可能组合

- 所属模块：cycle 状态机，区域 A 与区域 B
- 检测手段：双区域守卫矩阵在转移前校验；非法组合断言失败。
- 系统响应：拒绝转移并进 FAULT，软硬按是否安全相关分类；跨区守卫矩阵阻止区域 B 质量不足时进入
  PRELOAD 及之后。
- 严重度：高
- 是否已有缓解：有设计。双区域把非法空间从 11×7 收敛到守卫矩阵，待单元测试覆盖。

### FM-14 观测链路失效

- 所属模块：vision、取帧
- 检测手段：摄像头初始化失败；连续取帧失败计数达到 OBS_LINK_FAIL_N。
- 系统响应：OBS_LINK(5) 软故障 → FAULT → SAFE → HOME；禁止 AIM_ALLOWED 与 RELEASE。
- 严重度：中
- 是否已有缓解：有。代码已实现；架构 §6.9 第 12 条要求初始化失败走受限分支，不继续推进周期。

---

## 四、没有检测手段的失效模式

以下条目当前没有在线或自动检测手段，需要在后续设计里补传感或补判据：

- FM-03 膜片破裂：只有实验后目视与气密检查，运行中无在线检测。
- FM-04 弹性元件疲劳：靠离线 force-displacement 与寿命阶梯，运行中无在线检测。
- FM-06 双片：无专用传感器，只能靠人工与视频。
- FM-08 FIRE_INHIBIT 短路到高：无检测，且无有效缓解。
- FM-15 开环舵机非归零时段卡死：见下节，架构 §6.10 已指出判据不适用，当前无检测手段。

其中 FM-08 与 FM-15 同时属于风险台账里「没有有效缓解」的项。

### FM-15 开环舵机非归零时段卡死（补充条目）

- 所属模块：云台（pan、tilt）
- 检测手段：**无检测手段**。架构 §6.10 指出旧「速度长时间为零而 duty 高」判据在舵机上不适用；
  电流、母线电压跌落、到位超时、电流积分热模型等候选判据都还没标定。
- 系统响应：无自动响应。可能静默失位或停在错误指向继续动作；只有卡死发生在储能态或与机构卡死耦合时
  才升级 FAULT。
- 严重度：高
- 是否已有缓解：无。候选判据存在但未验证，标记该轴退化并禁 AIM_ALLOWED 的逻辑也依赖这些判据。
  对应风险 RSK-06。

---

## 五、缺口闭合记录

原先本节列的五个缺口都已在枚举末尾追加对应码，未改动既有取值：

| 失效模式 | 原缺口用途 | 对应新码 | 分级 |
|---|---|---|---|
| FM-03 膜片破裂 | 膜片或气路异常 | `MEMBRANE_RUPTURE`(10) | 硬 |
| FM-06 双片 | 供给双片 | `DOUBLE_FEED`(11) | 软 |
| FM-08 FIRE_INHIBIT 短路 | 安全输入通道不一致或卡死 | `FIRE_INHIBIT_SHORT`(12) | 硬 |
| FM-09 I2C 总线卡死 | I2C 运行期事务失败 | `I2C_BUS_HANG`(13) | 硬 |
| FM-13 不可能组合 | 状态机守卫违约 | `STATE_ILLEGAL`(14) | 硬 |

分级取值以 `faultSeverity()` 为准：`MEMBRANE_RUPTURE`、`FIRE_INHIBIT_SHORT`、`I2C_BUS_HANG`、
`STATE_ILLEGAL` 锁存，`DOUBLE_FEED` 可在清障后清除。原表给 FM-03、FM-06 的严重度建议写作「中」，
这里按代码的实际分级落实。

仍未闭合的是 FM-04 弹性元件疲劳与 FM-15 开环舵机非归零时段卡死，两者属于测量或标定问题，
没有对应码，先补检测手段。FM-08 的失效本身有了码，但检测手段仍未实现，运行期还发现不了。

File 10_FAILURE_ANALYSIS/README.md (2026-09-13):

# 10_FAILURE_ANALYSIS

失效分析与 STOP 条件的记录。

规格书 §30 的五条 STOP 里，STOP-01（单级无可测优势）、STOP-02（双级更差）、STOP-03（边界无稳定差异）、
STOP-05（成本超 ¥50）是结论性或预算性判定，不进运行时故障，结论写在这里。STOP-04（供给盘频繁卡料）
是运行期软故障，判定与升级条件见统一架构方案 §6.8，发生记录也归到这里。

另外 §7 列了失稳单元本身的失效模式，§11 的机械安全互锁失效如果实验里真出现，按现象、复现条件、
怀疑原因、处置分条记，附上 `08_DATA/` 里的数据位置。没复现的记录不要写成结论。

确认要放弃某条路线时，把被放弃的机构和对应实验一并写清楚，别只删相关代码和目录。

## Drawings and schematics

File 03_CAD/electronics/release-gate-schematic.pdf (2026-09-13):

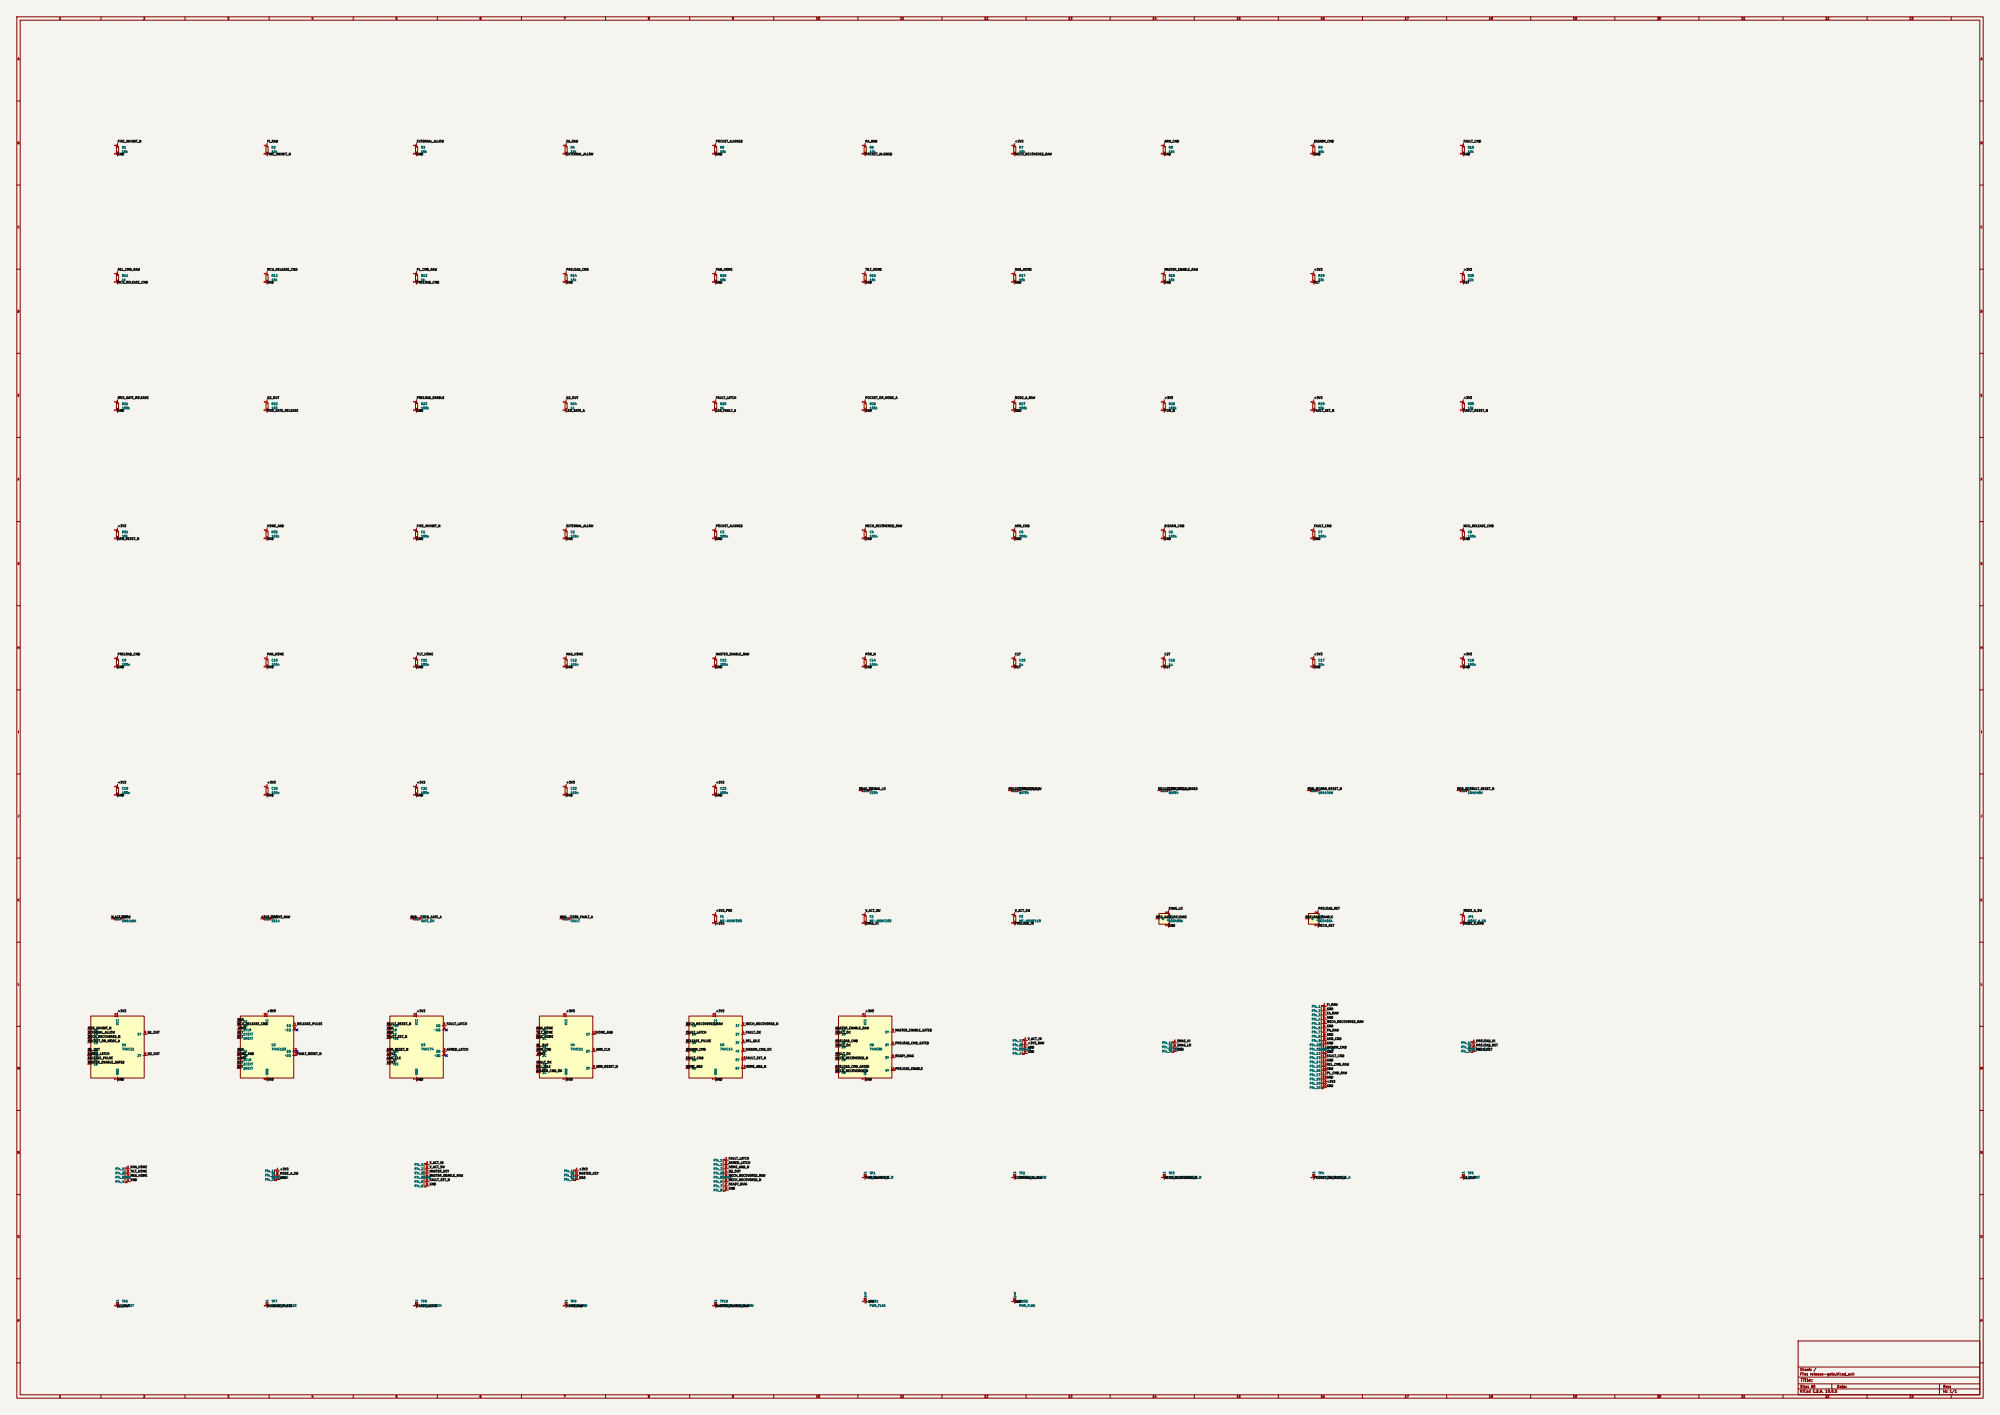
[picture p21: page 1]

Size: A0 | Rev:
KiCad E.D.A. 10.0.5 | Id: 1/1

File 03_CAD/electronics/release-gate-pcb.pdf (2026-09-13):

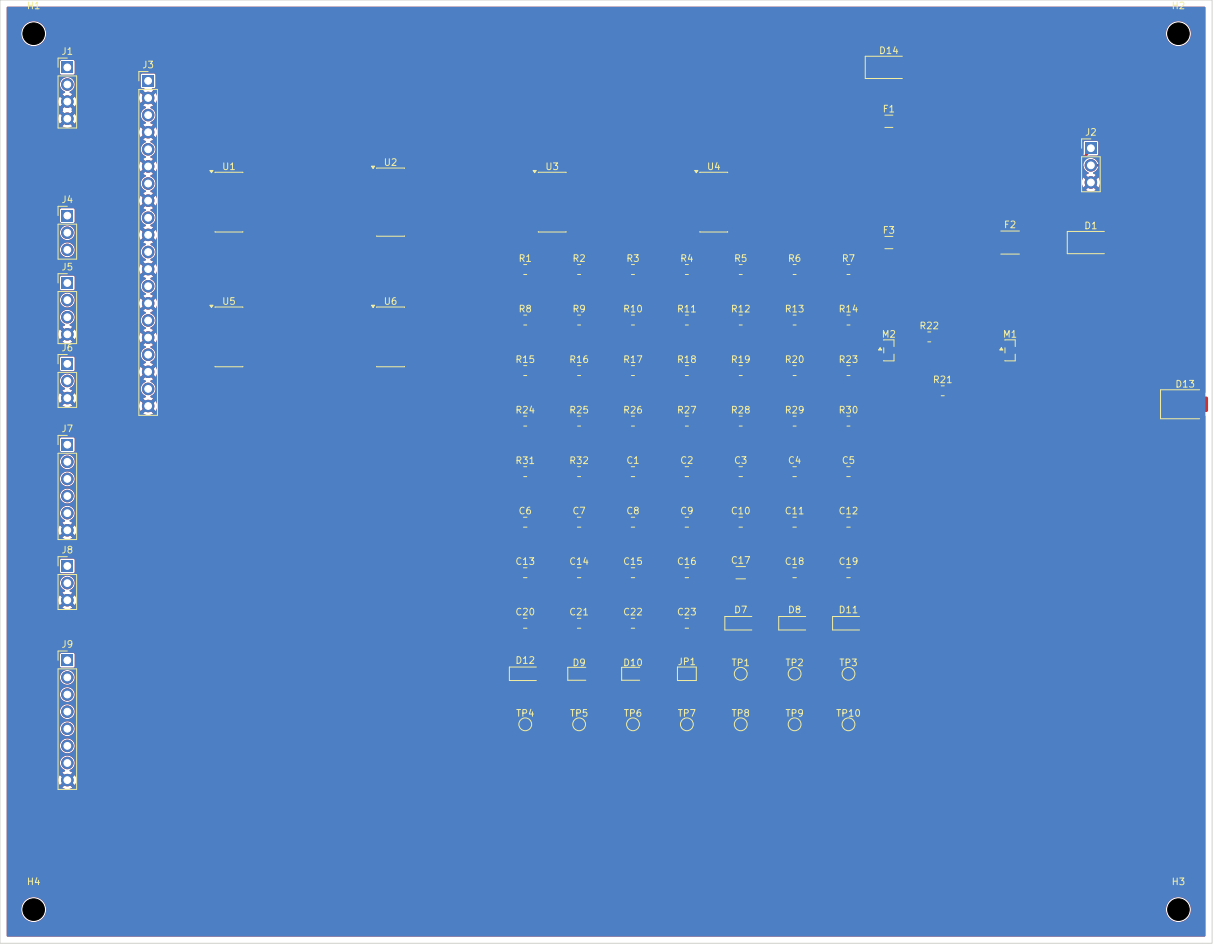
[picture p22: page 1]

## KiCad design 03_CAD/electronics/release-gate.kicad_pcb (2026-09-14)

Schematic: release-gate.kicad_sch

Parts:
C1, C2, C3, C4, C5, C6, C7, C8, C9, C10, C11, C12, C13, C14, C18, C19, C20, C21, C22, C23: 100n; C_0805_2012Metric
C15, C16: 1u; C_0805_2012Metric
C17: 10u; C_1206_3216Metric
D1: SS34; D_SMA
D7, D8: BAT54W; D_SOD-123
D9: GATE_OK; LED_0805_2012Metric
D10: FAULT; LED_0805_2012Metric
D11, D12: 1N4148W; D_SOD-123
D13: SMBJ16A; D_SMB
D14: SS14; D_SMA
F1: MF-MSMF050; Fuse_1206_3216Metric
F2: MF-MSMF200; Fuse_1812_4532Metric
F3: MF-MSMF110; Fuse_1206_3216Metric
J1: PWR_IN; PinHeader_1x04_P2.54mm_Vertical
J2: ACT_OUT; PinHeader_1x03_P2.54mm_Vertical
J3: SAFETY_IN; PinHeader_1x20_P2.54mm_Vertical
J4: PRELOAD_OUT; PinHeader_1x03_P2.54mm_Vertical
J5: HOME; PinHeader_1x04_P2.54mm_Vertical
J6: MODE_MAG; PinHeader_1x03_P2.54mm_Vertical
J7: ESTOP; PinHeader_1x06_P2.54mm_Vertical
J8: KEY; PinHeader_1x03_P2.54mm_Vertical
J9: STATUS; PinHeader_1x08_P2.54mm_Vertical
JP1: MODE_A_EN; SolderJumper-2_P1.3mm_Open_Pad1.0x1.5mm
M1, M2: AO3400A; SOT-23
PWR1, PWR2: PWR_FLAG
R1, R2, R3, R4, R5, R6, R7, R8, R9, R10, R12, R14, R15, R16, R17, R18, R29, R30, R31: 10k; R_0805_2012Metric
R11, R13, R24, R25: 1k; R_0805_2012Metric
R19: 33k; R_0805_2012Metric
R20: 22k; R_0805_2012Metric
R21, R23, R26, R27, R28, R32: 100k; R_0805_2012Metric
R22: 100; R_0805_2012Metric
TP1: FIRE_INHIBIT_N; TestPoint_Pad_D1.5mm
TP2: EXTERNAL_ALLOW; TestPoint_Pad_D1.5mm
TP3: MECH_RECOVERED_N; TestPoint_Pad_D1.5mm
TP4: POCKET_OR_MODE_A; TestPoint_Pad_D1.5mm
TP5: Q1_OUT; TestPoint_Pad_D1.5mm
TP6: Q2_OUT; TestPoint_Pad_D1.5mm
TP7: RELEASE_PULSE; TestPoint_Pad_D1.5mm
TP8: FAULT_LATCH; TestPoint_Pad_D1.5mm
TP9: HOME_AND; TestPoint_Pad_D1.5mm
TP10: MASTER_ENABLE_RAW; TestPoint_Pad_D1.5mm
U1: 74HC21; SOIC-14_3.9x8.7mm_P1.27mm
U2: 74HC123; SOIC-16_3.9x9.9mm_P1.27mm
U3: 74HC74; SOIC-14_3.9x8.7mm_P1.27mm
U4: 74HC11; SOIC-14_3.9x8.7mm_P1.27mm
U5: 74HC14; SOIC-14_3.9x8.7mm_P1.27mm
U6: 74HC08; SOIC-14_3.9x8.7mm_P1.27mm

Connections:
+3V3: C17.1, C18.1, C19.1, C20.1, C21.1, C22.1, C23.1, F1.2, J3.19, J6.1, J8.1, PWR1.1, R7.1, R19.1, R20.1, R28.1, R29.1, R30.1, R31.1, U1.14 (VCC), U2.3 (1CLR), U2.11 (2CLR), U2.16 (VCC), U3.10 (~2S), U3.12 (2D), U3.14 (VCC), U4.5 (2C), U4.14 (VCC), U5.14 (VCC), U6.14 (VCC)
+3V3_PRE: D14.1 (K), F1.1
+3V3_RAW: D14.2 (A), J1.2
ARMED_LATCH: J9.2, U1.10 (2B), U3.9 (2Q)
ARM_CLK: U3.11 (2C), U4.6 (2Y)
ARM_CMD: C5.1, J3.9, R8.1, U4.4 (2B)
ARM_RESET_N: D11.2 (A), R31.2, U3.13 (~2R), U4.8 (3Y)
C1T: C15.1, U2.6 (1CEXT)
C2T: C16.1, U2.14 (2CEXT)
DISARM_CMD: C6.1, J3.11, R9.1, U5.9 (4A)
DISARM_CMD_OK: U4.11 (3C), U5.8 (4Y)
EA_RAW: J3.3, R4.1
EMAG_HI: D1.1 (K), F2.2, J2.1
EMAG_LO: D1.2 (A), J2.2, M1.3 (D)
EXTERNAL_ALLOW: C2.1, R3.1, R4.2, TP2.1, U1.2 (1B)
FAULT_CMD: C7.1, J3.13, R10.1, U5.11 (5A)
FAULT_LATCH: J9.1, R25.1, TP8.1, U3.5 (1Q), U5.3 (2A)
FAULT_OK: U4.9 (3A), U5.4 (2Y), U6.2 (1B), U6.5 (2B), U6.9 (3A)
FAULT_RESET_N: D12.2 (A), R30.2, U2.13 (~2Q), U3.1 (~1R)
FAULT_SET_N: J7.5, R29.2, U3.4 (~1S), U5.10 (5Y)
FIRE_INHIBIT_N: C1.1, R1.1, R2.2, TP1.1, U1.1 (1A)
FI_RAW: J3.1, R2.1
GND: C1.2, C2.2, C3.2, C4.2, C5.2, C6.2, C7.2, C8.2, C9.2, C10.2, C11.2, C12.2, C13.2, C14.2, C17.2, C18.2, C19.2, C20.2, C21.2, C22.2, C23.2, D9.1 (K), D10.1 (K), D13.2 (A), J1.3, J1.4, J2.3, J3.2, J3.4, J3.6, J3.8, J3.10, J3.12, J3.14, J3.16, J3.18, J3.20, J5.4, J6.3, J7.6, J8.3, J9.8, M1.2 (S), PWR2.1, R1.2, R3.2, R5.2, R8.2, R9.2, R10.2, R12.2, R14.2, R15.2, R16.2, R17.2, R18.2, R21.2, R23.2, R26.2, R27.2, R32.2, U1.7 (GND), U2.1 (1A), U2.8 (GND), U2.9 (2A), U3.2 (1D), U3.3 (1C), U3.7 (GND), U4.7 (GND), U5.7 (GND), U6.7 (GND)
HOME_AND: R32.1, TP9.1, U2.10 (2B), U4.12 (1Y), U5.13 (6A)
HOME_AND_N: J9.3, U5.12 (6Y)
LED_FAULT_A: D10.2 (A), R25.2
LED_GATE_A: D9.2 (A), R24.2
MAG_HOME: C12.1, J5.3, R17.1, U4.13 (1C)
MASTER_ENABLE_GATED: U1.13 (2D), U6.3 (1Y)
MASTER_ENABLE_RAW: C13.1, J7.4, R18.1, TP10.1, U6.1 (1A)
MASTER_KEY: J7.3, J8.2
MCU_RELEASE_CMD: C8.1, R11.2, R12.1, U2.2 (1B)
MECH_RECOVERED_N: J9.6, TP3.1, U1.4 (1C), U5.2 (1Y), U6.10 (3B), U6.13 (4B)
MECH_RECOVERED_RAW: C4.1, J3.5, J9.5, R7.2, U5.1 (1A)
MECH_RET: J4.3, M2.2 (S)
MODE_A_RAW: D7.2 (A), JP1.2, R27.1
MODE_A_SW: J6.2, JP1.1
MOS_GATE_RELEASE: M1.1 (G), R21.1, R22.2
PAN_HOME: C10.1, J5.1, R15.1, U4.1 (1A)
PA_RAW: J3.7, R6.1
PL_CMD_RAW: J3.17, R13.1
POCKET_ALIGNED: C3.1, D8.2 (A), R5.1, R6.2
POCKET_OR_MODE_A: D7.1 (K), D8.1 (K), R26.1, TP4.1, U1.5 (1D)
POR_N: C14.1, D11.1 (K), D12.1 (K), R28.2
PRELOAD_CMD: C9.1, R13.2, R14.1, U6.4 (2A)
PRELOAD_CMD_GATED: U6.6 (2Y), U6.12 (4A)
PRELOAD_ENABLE: M2.1 (G), R23.1, U6.11 (4Y)
PRELOAD_HI: F3.2, J4.1
PRELOAD_RET: J4.2, M2.3 (D)
Q1_OUT: TP5.1, U1.6 (1Y), U1.9 (2A), U4.3 (2A)
Q2_OUT: J9.4, R22.1, R24.1, TP6.1, U1.8 (2Y)
R1T: C15.2, R19.2, U2.7 (1REXT)
R2T: C16.2, R20.2, U2.15 (2REXT)
READY_DIAG: J9.7, U6.8 (3Y)
RELEASE_PULSE: TP7.1, U1.12 (2C), U2.4 (1Q), U5.5 (3A)
REL_CMD_RAW: J3.15, R11.1
REL_IDLE: U4.10 (3B), U5.6 (3Y)
TILT_HOME: C11.1, J5.2, R16.1, U4.2 (1B)
V_ACT_IN: J1.1, J7.1
V_ACT_SW: D13.1 (K), F2.1, F3.1, J7.2

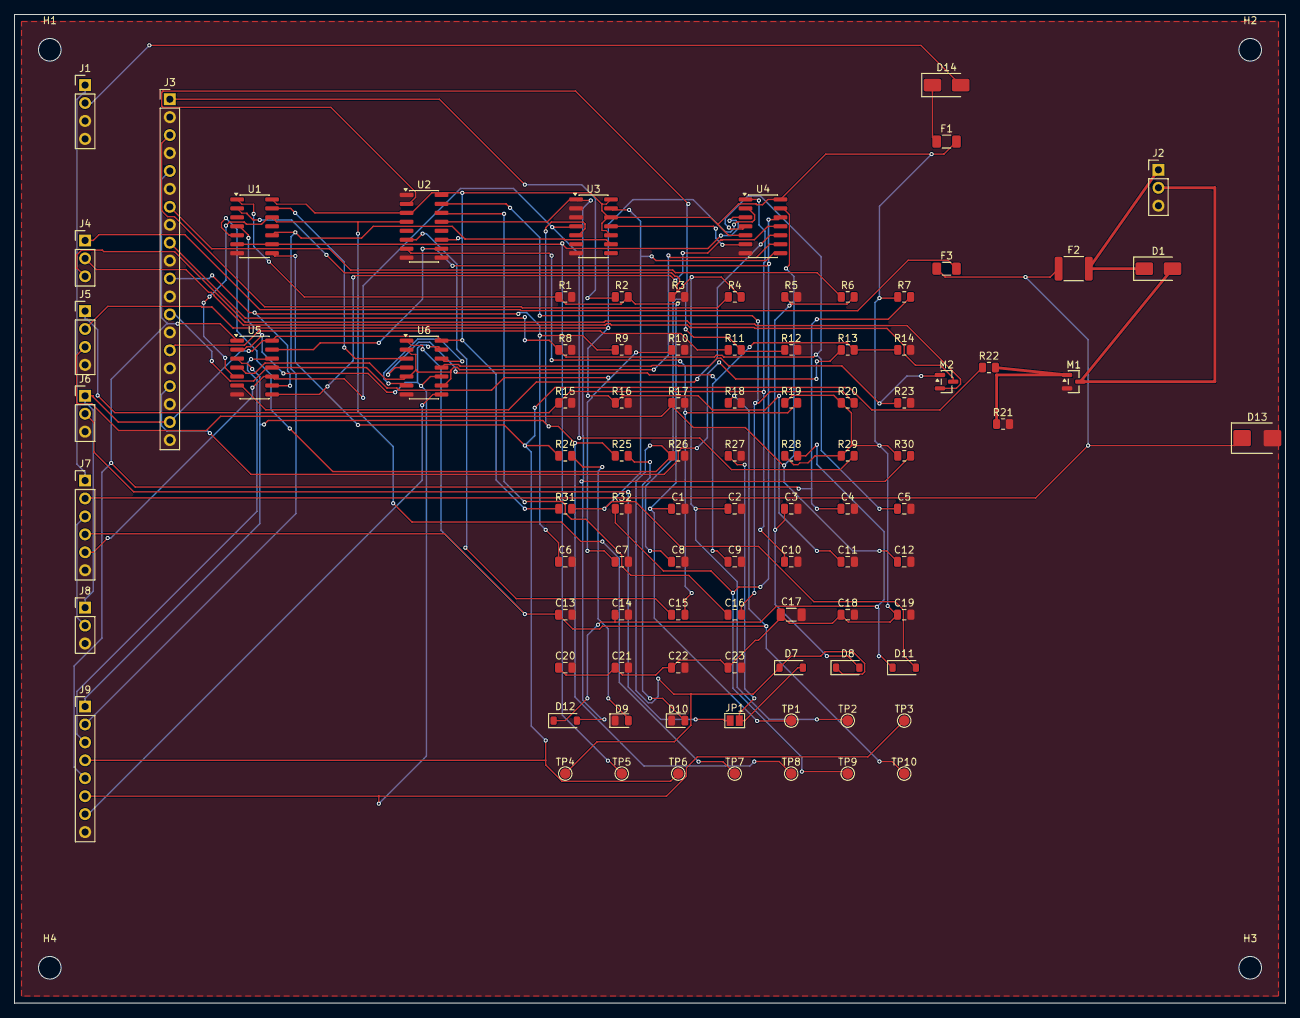
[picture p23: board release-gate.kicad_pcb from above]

Board: 2 copper layers, 180.0 x 140.0 mm, 99 parts (0 on the bottom side), 60 nets.

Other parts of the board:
H1, H2, H3, H4: MountingHole; MountingHole_3.2mm_M3

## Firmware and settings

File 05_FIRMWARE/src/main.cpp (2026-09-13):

/**
 * main.cpp
 * 固件入口与双区域状态机。区域 A（CycleState）管发射周期，区域 B（AimState）管
 * 指向质量，跨区域用守卫矩阵约束。上电初始化后按固定节拍跑"视觉->解算->指向->遥测"。
 *
 * 安全策略：
 *   1. 释放链只在全部互锁满足时导通，且真正的物理门控由外部与门保证（架构文档 §6.6）；
 *   2. setup() 期间释放链保持在禁止侧，归零完成前不使能；
 *   3. FAULT 锁存，唯一清除路径是 SAFE → HOME，FAULT → READY 这条边不存在；
 *   4. loop() 非阻塞，calibShellPoll() 放在最前，否则 100Hz 轮询会漏字符。
 */

#include <Arduino.h>

#include <cmath>
#include <cstdio>

#include "config.h"
#include "aim_types.h"
#include "data/batch_tags.h"
#include "calibration/calibration.h"
#include "comms/calib_shell.h"
#include "comms/telemetry.h"
#include "control/home.h"
#include "control/servo_axis.h"
#include "hal/io_expander.h"
#include "hal/safety_gate.h"
#include "hal/servo.h"
#include "math/angle_utils.h"
#include "vision/vision.h"

static CycleState s_cycle = CycleState::BOOT;
static AimState s_aim = AimState::IDLE;
static FaultCode s_fault = FaultCode::NONE;
static bool s_fault_latched = false;
static FireMode s_mode = (FireMode)FIRE_MODE_DEFAULT;

static bool s_vision_ok = false;
static bool s_cal_ok = false;
static CalibrationData s_cal;

// 批次追溯编号：由操作者经 SET 命令写入并存 NVS，上电读回。0 表示未设置。
static BatchTags s_batch;

static TargetObservation s_obs;
static uint32_t s_last_capture_ms = 0;
static uint32_t s_vision_frame_count = 0;
static uint32_t s_capture_fail_streak = 0;
static uint32_t s_frame_divider = 1;
static uint32_t s_overrun_streak = 0;

static uint32_t s_cycle_enter_ms = 0;
static uint32_t s_phase_start_ms = 0;
static uint32_t s_lock_start_ms = 0;
static uint32_t s_lock_start_frames = 0;
static uint32_t s_lock_lost_ms = 0;
static uint32_t s_cycle_count = 0;
static uint8_t s_mag_position = 0;
static uint8_t s_preload_state = 0;
static uint32_t s_index_attempts = 0;
static uint32_t s_index_phase_start_ms = 0;
static uint32_t s_release_start_ms = 0;
static bool s_prev_external_allow = false;

static volatile uint32_t s_stage1_us = 0;
static volatile uint32_t s_stage2_us = 0;
static volatile uint8_t s_stage1_count = 0;
static volatile uint8_t s_stage2_count = 0;

static char s_operator_note[24] = "-";

// alpha-beta 跟踪状态（作用于相对光轴的 bearing/elevation）。
static bool s_has_track = false;
static float s_bearing_deg = 0.0f;
static float s_elevation_deg = 0.0f;
static float s_bearing_rate_dps = 0.0f;
static float s_elevation_rate_dps = 0.0f;

static void enterFault(FaultCode code, const char* why);
static void changeCycle(CycleState next, const char* why);
static void setAim(AimState next, const char* why);
static void updateAimQuality(bool obs_fresh, uint32_t now_ms);
static bool faultClear();

static void releaseChainOff() {
    ioExpanderWritePin(EXP_PRELOAD_CMD_BIT, 0);
    ioExpanderWritePin(EXP_MAG_INDEX_CMD_BIT, 0);
    digitalWrite(RELEASE_CMD_PIN, LOW);
}

static void preloadSet(bool on) { ioExpanderWritePin(EXP_PRELOAD_CMD_BIT, on ? 1 : 0); }
static void magIndexSet(bool on) { ioExpanderWritePin(EXP_MAG_INDEX_CMD_BIT, on ? 1 : 0); }
static void stopPreload() {
    preloadSet(false);
    s_preload_state = 0;
}

static void setNote(const char* s) {
    std::snprintf(s_operator_note, sizeof(s_operator_note), "%s", s ? s : "-");
}

static void IRAM_ATTR stage1Isr() {
    s_stage1_us = micros();
    s_stage1_count++;
}
static void IRAM_ATTR stage2Isr() {
    s_stage2_us = micros();
    s_stage2_count++;
}

static void enterFault(FaultCode code, const char* why) {
    if (s_fault_latched) return; // 已锁存则保留首个故障码
    s_fault = code;
    s_fault_latched = true;

    // 统一入口：先断释放链与预载，再把舵机驱到安全位并保持力矩。
    // 不立即释能是因为开环 tilt 断电会因重力下坠（§6.9 第 13 条）。
    releaseChainOff();
    safetyLatchArmed(false);
    homeAbort();
    stopPreload();
    servoAxisFaultSafe();

    s_cycle = CycleState::FAULT;
    s_cycle_enter_ms = millis();
    setNote(why ? why : "fault");
    telemetryEmitEvent("FAULT", why ? why : "unknown");
}

// 区域 B 守卫矩阵（§6.1）：区域 B 决定区域 A 能走多远。
// 特例：已进入发射链（PRELOAD..INDEX）后按 §6.2 不再要求持续 LOCKED，
// 链内前进放行，锁定丢失由中止窗口处理；守卫只约束进入链之前。
static bool cycleGuardAllows(CycleState next) {
    const uint8_t cur = (uint8_t)s_cycle;
    if (cur >= (uint8_t)CycleState::PRELOAD && cur <= (uint8_t)CycleState::INDEX) {
        return true;
    }
    switch (s_aim) {
        case AimState::LOCKED:
            return true;
        case AimState::IDLE:
        case AimState::SEARCHING:
        case AimState::TRACKING:
        case AimState::CALIBRATING:
        case AimState::CALIB_MODE:
            return (uint8_t)next <= (uint8_t)CycleState::READY;
    }
    return false;
}

// 当前组合的合法性查询，与 cycleGuardAllows 职责分开：后者判「能否迁移到 next」，
// 这里判「当前 cycle/aim 组合是否本就不该存在」。把当前状态当作 next 喂回守卫，
// 复用同一张矩阵而不复制常量；FAULT 是任意时刻都合法的锁存态，单独放行。
static bool cycleStateLegal() {
    if (s_cycle == CycleState::FAULT) return true;
    return cycleGuardAllows(s_cycle);
}

static void changeCycle(CycleState next, const char* why) {
    if (next == s_cycle) return;
    if (next != CycleState::FAULT && !cycleGuardAllows(next)) {
        telemetryEmitEvent("GUARD", why ? why : "blocked");
        return;
    }
    // 离开含能态统一卸载：解除武装锁存。
    if (s_cycle == CycleState::ARMED && next != CycleState::RELEASE) {
        safetyLatchArmed(false);
    }
    if (next == CycleState::READY || next == CycleState::SAFE) {
        releaseChainOff();
    }
    s_cycle = next;
    s_cycle_enter_ms = millis();
    telemetryEmitEvent("STATE", why ? why : "");
}

static void setAim(AimState next, const char* why) {
    if (next == s_aim) return;
    s_aim = next;
    telemetryEmitEvent("AIM", why ? why : "");
}

// 故障清除：软故障才接受，只把系统送到 SAFE，随后由 SAFE → HOME 真实归零恢复。
// 硬故障软件清除无效；FAULT → READY 这条边不存在。
static bool faultClear() {
    if (!s_fault_latched) return false;
    if (faultSeverity(s_fault) == FaultSeverity::HARD) {
        telemetryEmitEvent("FAULT", "clear rejected: hard fault");
        return false;
    }
    s_fault_latched = false;
    s_fault = FaultCode::NONE;
    setNote("fault cleared");
    changeCycle(CycleState::SAFE, "fault cleared -> SAFE");
    return true;
}

static void updateAimQuality(bool obs_fresh, uint32_t now_ms) {
    if (s_aim == AimState::CALIB_MODE) return;
    if (!s_cal_ok) {
        setAim(AimState::CALIBRATING, "calibration invalid");
        return;
    }
    if (!obs_fresh) {
        s_lock_start_ms = 0;
        s_lock_lost_ms = (s_lock_lost_ms == 0) ? now_ms : s_lock_lost_ms;
        setAim(AimState::SEARCHING, "no observation");
        return;
    }
    if (servoAxisInDeadband()) {
        if (s_lock_start_ms == 0) {
            s_lock_start_ms = now_ms;
            s_lock_start_frames = s_vision_frame_count;
        }
        const bool window_ok = (now_ms - s_lock_start_ms) >= LOCK_WINDOW_MS;
        const bool frames_ok = (s_vision_frame_count - s_lock_start_frames) >= LOCK_MIN_VISION_FRAMES;
        if (window_ok && frames_ok) {
            setAim(AimState::LOCKED, "lock window satisfied");
        } else {
            setAim(AimState::TRACKING, "settling");
        }
    } else {
        s_lock_start_ms = 0;
        setAim(AimState::TRACKING, "tracking");
    }
}

// 视觉观测 -> 相对光轴角 -> alpha-beta -> 叠加到当前轴角。
static void updateTracking(const TargetObservation& obs, float dt_s) {
    if (s_aim == AimState::CALIB_MODE) return; // 标定时由 CAL JOG 直接给目标
    if (!obs.valid || obs.centroid.confidence <= 0.0f) return;

    float bearing_deg = 0.0f, elevation_deg = 0.0f;
    if (!calibrationPixelToAngles(s_cal, obs.centroid.x, obs.centroid.y,
                                  bearing_deg, elevation_deg)) {
        return;
    }

    if (!s_has_track) {
        s_bearing_deg = bearing_deg;
        s_elevation_deg = elevation_deg;
        s_bearing_rate_dps = 0.0f;
        s_elevation_rate_dps = 0.0f;
        s_has_track = true;
    } else {
        const float pred_b = s_bearing_deg + s_bearing_rate_dps * dt_s;
        const float pred_e = s_elevation_deg + s_elevation_rate_dps * dt_s;
        const float res_b = angleDiffDeg(pred_b, bearing_deg);
        const float res_e = angleDiffDeg(pred_e, elevation_deg);
        const float alpha = 0.50f; // 待实测标定
        const float beta = 0.20f;  // 待实测标定
        s_bearing_deg = pred_b + alpha * res_b;
        s_elevation_deg = pred_e + alpha * res_e;
        s_bearing_rate_dps += beta * res_b / dt_s;
        s_elevation_rate_dps += beta * res_e / dt_s;
    }

    const float cur_pan = servoAxisState(AXIS_PAN).position_deg;
    const float cur_tilt = servoAxisState(AXIS_TILT).position_deg;
    servoAxisSetTargetDeg(AXIS_PAN, cur_pan + s_bearing_deg);
    servoAxisSetTargetDeg(AXIS_TILT, cur_tilt + s_elevation_deg);
}

static void advanceCycle(uint32_t now_ms, bool obs_fresh) {
    switch (s_cycle) {
        case CycleState::BOOT:
            changeCycle(CycleState::SAFE, "boot");
            break;

        case CycleState::SAFE:
            // SAFE → HOME：上电与故障清除后都从这里开始归零。
            if (homeStart(now_ms)) {
                setAim(s_cal_ok ? AimState::SEARCHING : AimState::CALIBRATING, "homing");
                changeCycle(CycleState::HOME, "homing start");
            }
            break;

        case CycleState::HOME: {
            const HomeResult r = homeUpdate(now_ms);
            if (r == HomeResult::DONE) {
                // §6.10 步骤 5：归零完成后再校验标定数据。
                setAim(s_cal_ok ? AimState::SEARCHING : AimState::CALIBRATING, "homing done");
                changeCycle(CycleState::READY, "homing done");
            } else if (r == HomeResult::TIMEOUT) {
                enterFault(FaultCode::HOME_TIMEOUT, "home timeout");
            } else if (r == HomeResult::CONFLICT) {
                enterFault(FaultCode::HOME_SWITCH_CONFLICT, "home switch conflict");
            }
            break;
        }

        case CycleState::READY:
            updateAimQuality(obs_fresh, now_ms);
            if (s_aim == AimState::LOCKED) {
                changeCycle(CycleState::AIM_ALLOWED, "lock acquired");
            }
            break;

        case CycleState::AIM_ALLOWED:
            updateAimQuality(obs_fresh, now_ms);
            if (s_aim != AimState::LOCKED) {
                changeCycle(CycleState::READY, "lock lost");
                break;
            }
            // Interlock 1：机构复位才准预载。
            if (safetyCanEnterPreload()) {
                preloadSet(true);
                s_preload_state = 1;
                s_phase_start_ms = now_ms;
                s_lock_lost_ms = 0;
                changeCycle(CycleState::PRELOAD, "interlock1 ok");
            }
            break;

        case CycleState::PRELOAD:
            updateAimQuality(obs_fresh, now_ms);
            if (s_aim != AimState::LOCKED) {
                // 预载未完成且锁定丢失超过中止窗口：受控卸载退回 READY。
                if (s_lock_lost_ms == 0) s_lock_lost_ms = now_ms;
                if ((now_ms - s_lock_lost_ms) > PRELOAD_ABORT_MS) {
                    stopPreload();
                    s_lock_lost_ms = 0;
                    changeCycle(CycleState::READY, "lock lost abort");
                    break;
                }
            } else {
                s_lock_lost_ms = 0;
            }
            if (s_preload_state == 1 && (now_ms - s_phase_start_ms) >= PRELOAD_TIME_MS) {
                s_preload_state = 2;
                safetyLatchArmed(true); // 武装锁存参与 H1 与门
                changeCycle(CycleState::ARMED, "preload done");
            }
            break;

        case CycleState::ARMED: {
            updateAimQuality(obs_fresh, now_ms);
            const bool external = safetyExternalAllow();
            const bool rise = external && !s_prev_external_allow;
            s_prev_external_allow = external;
            // 释放前最后一瞬重新确认 LOCKED，并复查全部互锁（§6.5 H1 的软件侧）。
            if (s_aim == AimState::LOCKED &&
                (now_ms - s_cycle_enter_ms) >= ARMED_MIN_DWELL_MS &&
                (RELEASE_AUTO_ENABLED != 0 || rise)) {
                if (!safetyCanRelease()) {
                    enterFault(FaultCode::RELEASE_GATE_SELFTEST, "release interlock rejected");
                } else {
                    digitalWrite(RELEASE_CMD_PIN, HIGH);
                    s_release_start_ms = now_ms;
                    changeCycle(CycleState::RELEASE, "release");
                }
            }
            break;
        }

        case CycleState::RELEASE:
            if ((now_ms - s_release_start_ms) >= RELEASE_PULSE_MS) {
                releaseChainOff();
                safetyLatchArmed(false);
                changeCycle(CycleState::RECOVER, "release pulse done");
            }
            break;

        case CycleState::RECOVER:
            if (safetyMechRecovered()) {
                if (s_mode == FireMode::SOFT_PAYLOAD) {
                    s_index_attempts = 0;
                    s_index_phase_start_ms = now_ms;
                    magIndexSet(true);
                    changeCycle(CycleState::INDEX, "recovered, index");
                } else {
                    changeCycle(CycleState::READY, "recovered");
                }
            } else if ((now_ms - s_cycle_enter_ms) > RECOVER_TIMEOUT_MS) {
                enterFault(FaultCode::MECH_STUCK, "mechanism not recovered");
            }
            break;

        case CycleState::INDEX:
            if (safetyMagIndexOk()) {
                magIndexSet(false);
                s_mag_position = (uint8_t)((s_mag_position + 1) % MAG_POSITIONS);
                s_cycle_count++;
                changeCycle(CycleState::READY, "index ok");
            } else if ((now_ms - s_index_phase_start_ms) > INDEX_TIMEOUT_MS) {
                magIndexSet(false);
                s_index_attempts++;
                if (s_index_attempts >= INDEX_MAX_RETRY) {
                    // STOP-04：连续失败禁 Mode B，升级软故障。
                    s_mode = FireMode::AIR_ONLY;
                    enterFault(FaultCode::INDEX_FAIL, "index retries exhausted");
                } else {
                    s_index_phase_start_ms = now_ms;
                    magIndexSet(true);
                }
            }
            break;

        case CycleState::FAULT:
            break;
    }
}

static void shellGetObservation(TargetObservation& out) { out = s_obs; }
static void shellGetAxes(AxisState& pan, AxisState& tilt) { servoAxisGetState(pan, tilt); }
static AimState shellGetState() { return s_aim; }
static CycleState shellGetCycleState() { return s_cycle; }
static FaultCode shellGetFaultCode() { return s_fault; }
static CalibrationData* shellGetCalibration() { return &s_cal; }
static void shellApplyCalibration() { s_cal_ok = s_cal.valid; }
static void shellJog(float pan_deg, float tilt_deg) { servoAxisSetAxesDeg(pan_deg, tilt_deg); }
static void shellEmergencyStop() { enterFault(FaultCode::ESTOP, "shell estop"); }

static uint16_t shellGetMembraneId() { return s_batch.membrane_id; }
static uint16_t shellGetPayloadId() { return s_batch.payload_id; }

// 先改内存再落 NVS，写失败回退，保证参数校验失败或存储失败时都保持原值。
static bool shellSetMembraneId(uint16_t id) {
    const uint16_t prev = s_batch.membrane_id;
    s_batch.membrane_id = id;
    if (!batchTagsSave(s_batch)) {
        s_batch.membrane_id = prev;
        return false;
    }
    return true;
}

static bool shellSetPayloadId(uint16_t id) {
    const uint16_t prev = s_batch.payload_id;
    s_batch.payload_id = id;
    if (!batchTagsSave(s_batch)) {
        s_batch.payload_id = prev;
        return false;
    }
    return true;
}
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
void loop() {
    // 串口命令在最前面轮询：loop 未到控制节拍时会提前 return，
    // 放在这里才能按 UART 到达速率收字节，避免长命令被硬件 FIFO 丢掉。
    calibShellPoll();

    const uint32_t t_loop_start = micros();
    const uint32_t now_ms = millis();

    // 固定节拍：未到下一拍直接返回，绝不阻塞。
    static uint32_t next_us = 0;
    if (next_us == 0) {
        next_us = t_loop_start;
    }
    if ((int32_t)(t_loop_start - next_us) < 0) {
        return;
    }
    if ((int32_t)(t_loop_start - next_us) > (int32_t)((uint32_t)CONTROL_LOOP_BUDGET_MS * 1000u)) {
        next_us = t_loop_start;
    }
    next_us += (uint32_t)CONTROL_LOOP_BUDGET_MS * 1000u;

    // 输入采样每拍都做，故障态也刷新，便于 STATUS 显示现场电平。
    safetyGateUpdate(now_ms);

    // I2C0 运行期连续失败达到阈值：扩展器状态不再可信，判总线卡死（硬故障）。
    // 上一行的 safetyGateUpdate() 已在本拍完成读事务并刷新连续失败计数。
    if (!s_fault_latched && ioExpanderBusSuspectedHang()) {
        enterFault(FaultCode::I2C_BUS_HANG, "i2c0 bus hang");
    }

    // 失稳事件时间戳由中断捕获，这里把增量转成日志（§15.2 需要精确时间）。
    static uint8_t last_stage1_count = 0;
    static uint8_t last_stage2_count = 0;
    if (s_stage1_count != last_stage1_count) {
        last_stage1_count = s_stage1_count;
        char buf[24];
        std::snprintf(buf, sizeof(buf), "t=%luus", (unsigned long)s_stage1_us);
        telemetryEmitEvent("STAGE1", buf);
    }
    if (s_stage2_count != last_stage2_count) {
        last_stage2_count = s_stage2_count;
        char buf[24];
        std::snprintf(buf, sizeof(buf), "t=%luus", (unsigned long)s_stage2_us);
        telemetryEmitEvent("STAGE2", buf);
    }

    // 取帧（按目标帧率 + 看门狗降帧倍数节流）
    bool obs_fresh = false;
    bool obs_dropped = false; // 本拍尝试取帧但未得到有效观测
    if (!s_fault_latched && s_vision_ok) {
        const uint32_t vision_period_ms = (1000u / VISION_TARGET_FPS) * s_frame_divider;
        if ((now_ms - s_last_capture_ms) >= vision_period_ms) {
            s_last_capture_ms = now_ms;
            TargetObservation obs;
            if (visionCapture(obs) && obs.valid) {
                s_obs = obs; // 仅在有效时更新，避免无效帧覆盖上一有效观测
                s_vision_frame_count++;
                s_capture_fail_streak = 0;
            } else {
                obs_dropped = true;
                if (s_capture_fail_streak < 0xFFFFFFFFul) s_capture_fail_streak++;
            }
        }
    }
    if (s_obs.valid && (now_ms - s_obs.t_ms) <= OBS_TIMEOUT_MS) {
        obs_fresh = true;
    }

    // 双区域组合核对：守卫矩阵只约束迁移，这里补一次对当前稳定组合的核对，
    // 捕捉逻辑漏洞落进来的矩阵外组合。非法即进硬故障，并把当时的 A/B 取值留档。
    if (!s_fault_latched && !cycleStateLegal()) {
        char combo[32];
        std::snprintf(combo, sizeof(combo), "cycle=%u aim=%u",
                      (unsigned)s_cycle, (unsigned)s_aim);
        telemetryEmitEvent("STATE_ILLEGAL", combo);
        enterFault(FaultCode::STATE_ILLEGAL, combo);
    }

    if (!s_fault_latched) {
        advanceCycle(now_ms, obs_fresh);

        // 指向跟踪只在链上或 READY 态运行，归零/故障时由 home/fault 分支控制目标。
        const bool tracking_phase = (s_cycle == CycleState::READY ||
                                     s_cycle == CycleState::AIM_ALLOWED ||
                                     s_cycle == CycleState::PRELOAD ||
                                     s_cycle == CycleState::ARMED);
        if (tracking_phase) {
            const float dt_s = (float)CONTROL_LOOP_BUDGET_MS / 1000.0f;
            updateTracking(obs_fresh ? s_obs : TargetObservation(), dt_s);
        }
    }

    // 舵机指令下发，HOME 分支已在上面设好目标。
    servoAxisUpdate((float)CONTROL_LOOP_BUDGET_MS / 1000.0f);

    // 观测链路异常：连续取帧失败升级软故障。
    if (!s_fault_latched && s_capture_fail_streak >= OBS_LINK_FAIL_N) {
        enterFault(FaultCode::OBS_LINK, "capture link lost");
    }

    // 遥测：§19 的 17 个字段。
    TelemetryRecord rec;
    rec.timestamp = now_ms;
    rec.experiment_id = MST_EXPERIMENT_ID;
    rec.prototype_version = MST_PROTOTYPE_VERSION;
    rec.mechanism_version = MST_MECHANISM_VERSION;
    rec.mode = (uint8_t)s_mode;
    rec.boundary_state = MST_BOUNDARY_RESEARCH_ACTIVE;
    rec.preload_state = s_preload_state;
    rec.membrane_id = s_batch.membrane_id;
    rec.payload_id = s_batch.payload_id;
    rec.cycle_count = s_cycle_count;
    rec.stage1_event = s_stage1_count;
    rec.stage2_event = s_stage2_count;
    rec.mechanism_recovered = safetyMechRecovered() ? 1 : 0;
    rec.magazine_position = s_mag_position;
    rec.magazine_index_ok = safetyMagIndexOk() ? 1 : 0;
    rec.fault_code = (uint16_t)s_fault;
    rec.operator_note = s_operator_note;
    telemetryEmit(rec);

    // 看门狗：超预算只降帧；连续超预算或单拍严重超时直接进 FAULT（§6.9 第 9 条）。
    const uint32_t loop_us = micros() - t_loop_start;

    // 帧轨迹诊断行（DIAG,）：与上面的 MST, 各走各的，只服务指向精度、控制周期与锁定建立时间。
    // loop_us 量的是本拍计算耗时，不含遥测打印，避免打印本身抬高控制周期读值。
    {
        DiagRecord diag;
        diag.timestamp_ms = now_ms;
        diag.loop_us = loop_us;
        diag.obs_valid = obs_fresh ? 1 : 0;
        diag.obs_dropped = obs_dropped ? 1 : 0;
        if (obs_fresh) {
            diag.px = s_obs.centroid.x;
            diag.py = s_obs.centroid.y;
            diag.confidence = s_obs.centroid.confidence;
            float bearing_deg = 0.0f, elevation_deg = 0.0f;
            if (calibrationPixelToAngles(s_cal, diag.px, diag.py, bearing_deg, elevation_deg)) {
                diag.err_pan_deg = bearing_deg;
                diag.err_tilt_deg = elevation_deg;
                diag.err_deg = std::sqrt(bearing_deg * bearing_deg + elevation_deg * elevation_deg);
            }
        }
        const AxisState pan_state = servoAxisState(AXIS_PAN);
        const AxisState tilt_state = servoAxisState(AXIS_TILT);
        diag.pan_deg = pan_state.position_deg;
        diag.tilt_deg = tilt_state.position_deg;
        diag.pan_target_deg = pan_state.target_deg;
        diag.tilt_target_deg = tilt_state.target_deg;
        diag.aim_state = (uint8_t)s_aim;
        diag.has_feedback = (pan_state.has_feedback || tilt_state.has_feedback) ? 1 : 0;
        telemetryEmitDiag(diag);
    }

    if (loop_us > (uint32_t)CONTROL_LOOP_BUDGET_MS * 1000u) {
        if (s_overrun_streak < 0xFFFFFFFFul) s_overrun_streak++;
        if (s_overrun_streak == 1 || (s_overrun_streak % 50u) == 0u) {
            telemetryEmitEvent("WD", "loop over budget, reducing vision fps");
        }
        if (s_frame_divider < 8u) {
            s_frame_divider++;
        }
        if (!s_fault_latched &&
            (s_overrun_streak >= WATCHDOG_STREAK_N ||
             (loop_us / 1000u) > WATCHDOG_HARD_OVERRUN_MS)) {
            enterFault(FaultCode::WATCHDOG, "watchdog timeout");
        }
    } else {
        s_overrun_streak = 0;
        if (s_frame_divider > 1u) s_frame_divider--; // 恢复
    }
}

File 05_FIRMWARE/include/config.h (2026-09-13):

#pragma once
/**
 * config.h
 * 全局编译期配置：引脚、机械参数、控制器参数、安全阈值、通信参数。
 * 标注 "待实测标定" 的都是占位默认值，首次上电前按实物核对或整定。
 *
 * 第二期的执行层是舵机指向 + 两级脉冲核心 + 旋转供给盘，第一期的电机闭环、
 * TB6612、编码器层已整体删除，相关宏随之移除。全工程单向依赖本文件，
 * 硬件或整定值变化只改这里。
 */

// 构建版本：烧进镜像，启动横幅与遥测首行会打印，用于确认板上跑的是哪一版。
#define AIM_BUILD_VERSION "0.2.0"

// STOP-01/02 由实验结论决定是否需要回退单级：触发时把 STAGES 改回 1 并用构建
// 开关关掉双级相关功能，不进 FAULT。STOP-03 同理关闭边界研究分支。
#define MST_MECHANISM_STAGES             2      // 1=单级回退，2=双级串联
#define MST_PROTOTYPE_VERSION            "MST-01C"
#define MST_MECHANISM_VERSION            "MST-01C"
#define MST_RESEARCH_DUAL_STAGE_ENABLED  1
#define MST_RESEARCH_BOUNDARY_ENABLED    1
#define MST_BOUNDARY_RESEARCH_ACTIVE     0      // 运行期是否置起 BOUNDARY_CMD
#define MST_EXPERIMENT_ID                0

// 轴索引：全工程统一用它做数组下标/接口参数，避免散落 0/1 字面量。
#define AXIS_PAN   0
#define AXIS_TILT  1
#define AXIS_COUNT 2

// Y2..Y9 对应 esp32-camera 的 D0..D7，顺序不可打乱。不同 S3-CAM 板的线序差异很大，
// 接错不会烧板，但会黑屏/花屏，首次烧录前对照原理图确认。
#define CAM_PIN_PWDN        (-1)   // 待实测标定：-1 表示未接
#define CAM_PIN_RESET       (-1)   // 待实测标定：-1 表示未接
#define CAM_PIN_XCLK        15     // 待实测标定
#define CAM_PIN_SIOD        4      // 待实测标定
#define CAM_PIN_SIOC        5      // 待实测标定
#define CAM_PIN_Y9          16     // 待实测标定
#define CAM_PIN_Y8          17     // 待实测标定
#define CAM_PIN_Y7          18     // 待实测标定
#define CAM_PIN_Y6          12     // 待实测标定
#define CAM_PIN_Y5          10     // 待实测标定
#define CAM_PIN_Y4          8      // 待实测标定
#define CAM_PIN_Y3          9      // 待实测标定
#define CAM_PIN_Y2          11     // 待实测标定
#define CAM_PIN_VSYNC       6      // 待实测标定
#define CAM_PIN_HREF        7      // 待实测标定
#define CAM_PIN_PCLK        13     // 待实测标定

// 20MHz 是 OV2640 常用稳定值，提高会增大 EMI 与走线要求。
#define CAM_XCLK_FREQ_HZ    20000000

// XCLK 走 LEDC timer2/channel2。舵机 PWM 用 timer3 的 channel3/4，分开避免抢占。
#define CAM_LEDC_CHANNEL    2
#define CAM_LEDC_TIMER      2

// 机械限位（度）：pan ±180°，tilt -30~+60。
#define PAN_MIN_DEG        (-180.0f)
#define PAN_MAX_DEG        (180.0f)
#define TILT_MIN_DEG       (-30.0f)
#define TILT_MAX_DEG       (60.0f)

// 软限位提前量：进入限位前该角度内禁止继续朝限位运动，给减速留缓冲。
#define SOFT_LIMIT_MARGIN_DEG  2.0f

// 360° 环绕预留开关。默认 0（限位模式），角差按线性直接相减。置 1 进入环绕模式后
// 角度按 360° 周期处理，必须配滑环/无限位机械结构，切换前确认硬件允许连续旋转。
#define ANGLE_WRAP_360_ENABLED  0

// 控制节拍（Hz）。
#define CONTROL_LOOP_HZ         100
#define CONTROL_LOOP_BUDGET_MS  (1000 / CONTROL_LOOP_HZ)

// 进入该误差带且满足锁定窗口即 LOCKED。
#define PAN_DEADBAND_DEG    0.5f
#define TILT_DEADBAND_DEG   0.5f

// 指向角速度上限（度/秒）：单轴指令变化率限制，抑制舵机冲击与过冲。
#define PAN_MAX_SLEW_DPS    180.0f
#define TILT_MAX_SLEW_DPS   120.0f

// 有反馈舵机的位置校正比例。无反馈实现不使用。
#define SERVO_POS_CORR_KP   0.90f  // 待实测标定

// 上电归零安全位：进入闭环前先运动到此位，避开限位与遮挡。
#define CONTROL_HOME_PAN_DEG   0.0f
#define CONTROL_HOME_TILT_DEG  0.0f

// LOCKED 作发射门：改用时窗 + 多视觉帧确认，替代原来纯控制拍计数，
// 使判定口径与规格书 §11.1 的 ≤500ms 一致（对应 §6.9 第 14 条冲突）。
#define LOCK_WINDOW_MS          500
#define LOCK_MIN_VISION_FRAMES  3
// 保留的旧宏：纯控制拍计数已不作为发射门判据，供诊断参考。
#define LOCK_FRAMES_N       8

// 观测超时：超过则判定目标丢失并转 SEARCHING。
#define OBS_TIMEOUT_MS      500

// 两轴位置舵机。实现由 SERVO_DRIVE_TYPE 编译期选择，采购前不必冻结选型。
#define SERVO_DRIVE_PWM 0
#define SERVO_DRIVE_BUS 1
#define SERVO_DRIVE_TYPE SERVO_DRIVE_PWM   // 待实测标定

// PAN_CMD/TILT_CMD 直连 PWM，LEDC channel3/4 共用 timer3。
#define SERVO_PAN_PIN     14     // 待实测标定
#define SERVO_TILT_PIN    21     // 待实测标定
#define SERVO_PAN_LEDC_CHANNEL   3
#define SERVO_TILT_LEDC_CHANNEL  4
#define SERVO_LEDC_TIMER   3
#define SERVO_PWM_FREQ_HZ  50
#define SERVO_PWM_RESOLUTION_BITS 16
#define SERVO_PULSE_MIN_US 500.0f    // 待实测标定
#define SERVO_PULSE_MAX_US 2500.0f   // 待实测标定

// 脉宽端点对应的舵机轴角，用于角度↔脉宽换算。没有实测行程前先令其等于机械限位，
// 安装后按舵机铭牌与实测重复定位结果重标。
#define SERVO_PAN_MIN_DEG   PAN_MIN_DEG    // 待实测标定
#define SERVO_PAN_MAX_DEG   PAN_MAX_DEG    // 待实测标定
#define SERVO_TILT_MIN_DEG  TILT_MIN_DEG   // 待实测标定
#define SERVO_TILT_MAX_DEG  TILT_MAX_DEG   // 待实测标定

// 方向极性：正指令应使轴朝正方向运动，反了就置 1，不必改接线。
#define SERVO_INVERT_PAN    0    // 待实测标定
#define SERVO_INVERT_TILT   0    // 待实测标定

// 总线舵机（ServoBus）串口参数。协议未定，接入选型后补齐帧格式与命令字。
#define SERVO_BUS_UART_NUM  1        // 待实测标定
#define SERVO_BUS_TX_PIN    (-1)     // 待实测标定：与 UART1 可用脚一并确定
#define SERVO_BUS_RX_PIN    (-1)     // 待实测标定
#define SERVO_BUS_BAUD      1000000  // 待实测标定

#define HOME_TIMEOUT_MS      3000   // 步骤 3：3 秒内不触发即失败
#define HOME_SEEK_STEP_DEG   1.0f   // 每拍朝参考方向推进的角度
#define HOME_SEEK_PERIOD_MS  20
#define HOME_CONFIRM_MS      20     // 参考开关需稳定闭合的确认时间
#define HOME_SETTLE_MS       200    // 触发后退回已知角度的稳定等待
#define HOME_PAN_DIR        (-1)    // 待实测标定：参考开关所在方向，-1 朝最小角
#define HOME_TILT_DIR       (-1)    // 待实测标定
#define HOME_PAN_BACKOFF_DEG   5.0f // 待实测标定
#define HOME_TILT_BACKOFF_DEG  5.0f // 待实测标定

#define RELEASE_CMD_PIN     3        // 待实测标定，直连，strapping 脚
#define RELEASE_PULSE_MS    30       // 软件脉冲宽度；硬件单稳态另设上限（§6.6）
#define STAGE1_STATE_PIN    40       // 待实测标定，直连中断
#define STAGE2_STATE_PIN    41       // 待实测标定，直连中断
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

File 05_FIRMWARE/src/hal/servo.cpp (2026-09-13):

/**
 * servo.cpp
 * PWM 实现用 LEDC 出 50Hz 舵机信号；总线实现是占位骨架。
 *
 * 脉宽到占空比的换算：
 *   duty = 脉宽(us) × 1e-6 × 频率(Hz) × (2^分辨率 - 1)
 * 50Hz 周期对应 (2^16 - 1) 个计数，1500us 中位约 4915。
 */

#include "servo.h"

#include <Arduino.h>
#include <driver/ledc.h>
#include <cmath>

#include "config.h"

namespace {

// 把角度按本轴机械限幅夹紧。无反馈舵机指令越界会撞止挡，必须在最底层拦住。
float clampAxisDeg(uint8_t axis, float deg) {
    const float lo = (axis == AXIS_PAN) ? PAN_MIN_DEG : TILT_MIN_DEG;
    const float hi = (axis == AXIS_PAN) ? PAN_MAX_DEG : TILT_MAX_DEG;
    if (!std::isfinite(deg)) return lo; // 非有限值一律收到最小角，避免野值
    if (deg < lo) return lo;
    if (deg > hi) return hi;
    return deg;
}

float axisInvert(uint8_t axis) {
    if (axis == AXIS_PAN) return (SERVO_INVERT_PAN != 0) ? -1.0f : 1.0f;
    return (SERVO_INVERT_TILT != 0) ? -1.0f : 1.0f;
}

float axisServoMinDeg(uint8_t axis) {
    return (axis == AXIS_PAN) ? SERVO_PAN_MIN_DEG : SERVO_TILT_MIN_DEG;
}

float axisServoMaxDeg(uint8_t axis) {
    return (axis == AXIS_PAN) ? SERVO_PAN_MAX_DEG : SERVO_TILT_MAX_DEG;
}

class ServoPwm : public ServoDrive {
public:
    bool init() override {
        ledc_timer_config_t tcfg = {};
        tcfg.speed_mode = LEDC_LOW_SPEED_MODE;
        tcfg.duty_resolution = (ledc_timer_bit_t)SERVO_PWM_RESOLUTION_BITS;
        tcfg.timer_num = (ledc_timer_t)SERVO_LEDC_TIMER;
        tcfg.freq_hz = SERVO_PWM_FREQ_HZ;
        tcfg.clk_cfg = LEDC_AUTO_CLK;
        if (ledc_timer_config(&tcfg) != ESP_OK) {
            Serial.println("[servo] LEDC 定时器配置失败");
            return false;
        }

        const int channels[AXIS_COUNT] = { SERVO_PAN_LEDC_CHANNEL, SERVO_TILT_LEDC_CHANNEL };
        const int pins[AXIS_COUNT] = { SERVO_PAN_PIN, SERVO_TILT_PIN };
        for (int i = 0; i < AXIS_COUNT; ++i) {
            ledc_channel_config_t ccfg = {};
            ccfg.gpio_num = pins[i];
            ccfg.speed_mode = LEDC_LOW_SPEED_MODE;
            ccfg.channel = (ledc_channel_t)channels[i];
            ccfg.timer_sel = (ledc_timer_t)SERVO_LEDC_TIMER;
            ccfg.duty = 0; // 先无脉冲，等第一次写角度再输出
            ccfg.hpoint = 0;
            if (ledc_channel_config(&ccfg) != ESP_OK) {
                Serial.printf("[servo] LEDC 通道配置失败 channel=%d\n", channels[i]);
                return false;
            }
        }
        initialized_ = true;
        torque_ = false; // 上电默认失能，归零流程开始时再使能
        return true;
    }

    void writePanDeg(float deg) override { write(AXIS_PAN, deg); }
    void writeTiltDeg(float deg) override { write(AXIS_TILT, deg); }

    float readPanDeg() override { return last_deg_[AXIS_PAN]; }
    float readTiltDeg() override { return last_deg_[AXIS_TILT]; }

    bool hasFeedback() const override { return false; }

    void setTorqueEnabled(bool enable) override {
        if (!initialized_) return;
        torque_ = enable;
        if (enable) {
            // 重新使能时恢复上次指令角，避免中间态。
            output(AXIS_PAN, last_deg_[AXIS_PAN]);
            output(AXIS_TILT, last_deg_[AXIS_TILT]);
        } else {
            outputRaw(SERVO_PAN_LEDC_CHANNEL, 0);
            outputRaw(SERVO_TILT_LEDC_CHANNEL, 0);
        }
    }

    void emergencyRelease() override {
        torque_ = false;
        if (!initialized_) return;
        outputRaw(SERVO_PAN_LEDC_CHANNEL, 0);
        outputRaw(SERVO_TILT_LEDC_CHANNEL, 0);
    }

private:
    void write(uint8_t axis, float deg) {
        last_deg_[axis] = clampAxisDeg(axis, deg);
        if (initialized_ && torque_) {
            output(axis, last_deg_[axis]);
        }
    }

    void output(uint8_t axis, float clamped_deg) {
        const int channel = (axis == AXIS_PAN) ? SERVO_PAN_LEDC_CHANNEL : SERVO_TILT_LEDC_CHANNEL;
        outputRaw(channel, angleToPulseUs(axis, clamped_deg));
    }

    static uint32_t angleToPulseUs(uint8_t axis, float clamped_deg) {
        const float lo = axisServoMinDeg(axis);
        const float hi = axisServoMaxDeg(axis);
        float t = 0.0f;
        if (hi > lo) {
            // 先套方向极性，再按电气行程归一。方向只影响斜率符号。
            const float d = clamped_deg * axisInvert(axis);
            t = (d - lo) / (hi - lo);
        }
        if (t < 0.0f) t = 0.0f;
        if (t > 1.0f) t = 1.0f;
        const float pulse = SERVO_PULSE_MIN_US + t * (SERVO_PULSE_MAX_US - SERVO_PULSE_MIN_US);
        const uint32_t max_duty = (1u << SERVO_PWM_RESOLUTION_BITS) - 1u;
        const double duty = (double)pulse * 1e-6 * (double)SERVO_PWM_FREQ_HZ * (double)max_duty;
        uint32_t v = (uint32_t)(duty + 0.5);
        if (v > max_duty) v = max_duty;
        return v;
    }

    static void outputRaw(int channel, uint32_t duty) {
        ledc_set_duty(LEDC_LOW_SPEED_MODE, (ledc_channel_t)channel, duty);
        ledc_update_duty(LEDC_LOW_SPEED_MODE, (ledc_channel_t)channel);
    }

    bool initialized_ = false;
    bool torque_ = false;
    float last_deg_[AXIS_COUNT] = { 0.0f, 0.0f };
};
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

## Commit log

2026-09-13 初始提交：ESP32-S3 双轴目标锁定舵盘
    固件的可编译骨架。PlatformIO 工程，开发与发布双环境，目标板 ESP32-S3 N16R8
    走 OPI PSRAM。两个轴各一台 JGB37-520 减速电机，自带霍尔编码器，共用一片
    TB6612FNG 驱动。编码器走 PCNT 硬件四倍频解码，不占 CPU。控制用位置环加
    速度环的双环 PID，带抗积分饱和、微分低通、死区和占空比限幅。
    角度运算全部走 angle_utils，环绕与否由调用方按轴的机械形态显式传入，不读
    全局宏。将来换滑环做 360 度连续旋转只改 config.h 一个数字。
    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
    [sample_track.csv]
2026-09-13 第二期准备：标定工具链、固件标定模式、注释精简、统一架构
    固件
    - 新增串口标定外壳 calib_shell：CAL START/JOG/MARK/LIST/DEL/CLEAR/SOLVE/SAVE/LOAD/EXIT
    加 ESTOP，非阻塞轮询，32 点表，训练点与留出点分开报 RMSE
    - AimState 追加 CALIB_MODE，加在枚举末尾。前面的取值不变，遥测与 PC 脚本的数值映射
    不受影响，同时保持 CALIBRATING 原有的"标定无效"语义
    - config.h 新增引脚与资源预留分区。只增注释，未改任何已有宏名与宏值，避免打断按正则
    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
    [calibrate_axis_config.h.txt, sample_axis_points.csv]
2026-09-13 补全统一架构的状态机与安全互锁设计
    状态机改为双区域
    - 发射周期 11 态与指向质量 6 态分别建模，跨区域用守卫矩阵约束。拉平成一个枚举会得到
    11x7 的状态空间，其中绝大多数组合非法，用缺席表达非法组合，漏判一次就进入不可能状态
    - 确定 AIM_ALLOWED 与 LOCKED 的关系：LOCKED 是入场条件，进入后并存。RELEASE 前重新
    确认 LOCKED，这是指向与发射许可之间唯一且必须存在的耦合点
    - 标定态限制在 READY 及以下，软件守卫加状态拒绝加硬件断链三层
    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
2026-09-13 按 MST-01 §20 重组仓库目录
    - 建立 00_MASTER_SPEC 到 11_PUBLICATION_NOTES 的完整骨架
    - firmware/ 整体移入 05_FIRMWARE/，PlatformIO 工程结构不变
    - algo_reference/ 移入 05_FIRMWARE/algo_reference/，与固件配对，便于交叉引用
    - tools/ 移入 07_EXPERIMENTS/tools/
    - 方案设计、标定与几何推导、硬件接线与选型归入 02_REQUIREMENTS
    - 统一架构方案归入 00_MASTER_SPEC
    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
    [calibrate_axis_config.h.txt, sample_axis_points.csv, sample_track.csv]
2026-09-13 第二期固件落地：电机闭环换舵机，双区域状态机，补齐 §20 交付物
    - 删除电机、编码器、双环 PID 执行层共 10 个文件：motor_driver、encoder、axis、
    turntable、pid
    - 新增舵机驱动 ServoDrive 抽象，PWM 与总线两个实现用编译期开关选型。
    总线协议未定，只留接口与骨架，不臆造帧格式
    - 新增 MCP23017 扩展器、软件互锁 safety_gate、单轴指向 servo_axis、上电归零 home
    - 状态机改双区域：CycleState 十一态用规格书 §10.1 的名字，AimState 六态保留一期
    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
    [bom.csv]
2026-09-13 补齐规格书 §33 要求的规划与接口类交付物
    新增
    - 02_REQUIREMENTS/interfaces.md：对外电气接口、机械接口、扩展器接口、上位机接口、
    硬件安全门接口、接口变更流程。含开路与掉电与短路三种失效下的行为表
    - 02_REQUIREMENTS/safety-boundary.md：允许与禁止清单、四道硬件互锁、故障分级、
    五条 STOP 条件的归属、上电归零期间的强制安全态、单点失效分析、表述纪律
    - 02_REQUIREMENTS/RISK_REGISTER.md：十五条风险，分安全、技术、成本、进度四组
    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
2026-09-13 CAD 与故障码同步
    CAD
    - 03_CAD/lib 参数库补上纯 Python STL 写出与读回校验，不依赖 FreeCAD
    - MST-01A 到 C 三级加上 --stl 开关，导出逐件 STL 与整装 STL
    - 导出结果：A 17 个文件、B 32 个、C 42 个
    - 校验：整装 STL 体积与解析体积偏差 0.018 到 0.021 个百分点，逐件最大偏差 0.161 个百分点，
    来源是圆柱按 64 段多边形逼近。零面积三角形 0，法向异常 0，逐件为闭合可定向流形
    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
    [ACTUATOR_body.stl, ACTUATOR_pushrod.stl, DIAPHRAGM_disc.stl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]
2026-09-13 释放门控板与故障触发点
    电子
    - 03_CAD/electronics 交付释放门控板：原理图 97 个符号实例 60 个网络、板图初版、
    95 行 BOM、23 条板级测试规程、设计说明
    - 与门树按架构 §6.6 用 74HC21 级联，含 74HC123 单稳态钳时、AO3400A 低边负载开关、
    74HC74 故障锁存与武装锁存、急停三触点、模式 A 旁路
    - 单稳态脉宽计算：释放 33ms，归零复位 22ms
    - 经 kicad-cli 10.0.5 实际解析：ERC 0 error、DRC 0 error，导出 PDF 与 SVG
    - 过程中修正一处真实设计错误：FAULT_CMD 反相输出原先未接到故障锁存置位端
    - 已知缺口：信号布线未完成，DRC 报 151 个未连接项；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
    [aim_types.h, calib_shell.cpp, calibration.h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]
2026-09-13 数值仿真、研究表述与双级机构的模型预警
    仿真
    - 04_SIMULATION 建立纯软件数值模型：膜片大挠度非线性、von Mises 双稳单元、
    两级串联链、速度 Verlet 瞬态积分，27 个模型性质测试全部通过
    - 覆盖规格书 §23 的准静态、瞬态、参数扫描三块，按 A、B、C 三级原型组织
    - 结果落盘 13 个 CSV，含三级瞬态轨迹与五组参数扫描
    模型给出的关键数字
    - 准静态：边界刚度从 2e2 扫到 1e5 N/m，单级 B 与双级 C 的 snap 阈值完全相同，差值为零
    - 准静态：C 的两级各距 fold 只有 0.008 mm，几乎同时跳变，静态分不出先后
    - 瞬态：膜片峰值速度 A 级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
    [A_force_displacement.csv, B_force_displacement.csv, C_force_displacement.csv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]
2026-09-13 补齐 D 与 E 级 CAD、恢复验收指标、记录两处几何冲突
    CAD 五级齐备
    - 03_CAD/lib 扩展出 BOUNDARY_MODULE、PRELOAD_MODULE、MAGAZINE_MODULE 三组参数与几何模块
    - 新增 MST-01D 可切换边界研究版与 MST-01E 自动供给完整版，各级含 build.py 与 README
    - D 级与 E 级都支持单级与双级两种核心，级数作为参数
    - 导出 STL：D 级 54 个、E 级 79 个。A/B/C 回归通过，未被改坏
    - 边界模块两种状态各由硬限位确定，不靠摩擦维持，可反复切换回到同一止点
    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
    [BOUNDARY_carriage.stl, BOUNDARY_detent_plunger.stl, BOUNDARY_guide_post_negx.stl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]
2026-09-13 释放门控板与五级 CAD 的收尾
    - 03_CAD/electronics 整体入库：原理图 97 个符号实例 60 个网络、板图、95 行 BOM、
    23 条板级测试规程、设计说明
    - 经 kicad-cli 10.0.5 解析：ERC 0 error 0 warning，DRC 0 error 0 warning
    - 已知缺口：信号布线未完成，DRC 报 151 个未连接项，另有 1 条丝印重叠。
    外形 181.8 x 144.3 毫米，属台架验证形态，与规格书 §1.2 的火柴盒级目标不符。
    缩小路径写在目录 README 里
    - 暂存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
    [bom.csv, release-gate.kicad_pcb, release-gate.kicad_sch]
2026-09-14 释放门控板自动布线，以及最终全量复验
    自动布线
    - 用 Freerouting 2.4.1 把板子布通：未连接项从 151 降到 23
    - 管线建立在命令行工具上，不依赖那个挂掉的 KiCad MCP：
    pcbnew 导出 Specctra DSN、freerouting 命令行布线、pcbnew 回导 SES、pcbnew 重灌铜箔
    - Freerouting 的无界面开关是 --gui.enabled=false。缺了它会试图拉 GUI，在无显示环境里挂死
    - 重灌铜箔这一步不能省。省掉的话铜箔没避让新走线，DRC 会把 511 处报成短路，
    实测是 733 条违规；重灌后降到 31 条
    - 铜箔焊盘连接由热焊盘改为实心，消掉了 11 条 starved_thermal
    残留问题，已写进电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
    [release-gate.kicad_pcb]
